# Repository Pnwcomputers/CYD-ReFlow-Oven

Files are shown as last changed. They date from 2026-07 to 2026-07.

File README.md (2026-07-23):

# 🌡️ DIY CYD Reflow Oven Controller

> **⚠️ SAFETY WARNING:** This project involves mains AC voltage, appliance modification, and high heat. Incorrect wiring can cause electric shock, fire, equipment damage, or severe injury. Do not attempt this unless you are experienced and comfortable working with mains AC wiring. Always verify wiring with a meter, confirm current ratings, use proper strain relief, bond ground correctly, and never leave the oven unattended while operating.

## 📖 Overview

This is a custom-built, cost-conscious reflow toaster oven controller designed for soldering Surface Mount Technology (SMT) printed circuit boards. It serves as a lower-cost alternative to reference designs like the [Adafruit EZ Make Oven](https://learn.adafruit.com/ez-make-oven/overview), leveraging the popular [**Cheap Yellow Display (CYD)**](https://www.elecrow.com/2-8inch-esp32-miner-lcd-display-2pcs-cryptocurrency-solo-miner-with-1000kh-s-hashrate.html) ESP32 touchscreen module.

The controller is housed in a standalone, 3D-printed bench enclosure sitting safely adjacent to the toaster oven.

### How It Works

* **Control:** Switches oven heating elements via a Solid State Relay (SSR) using slow-PWM control (2-second window).
* **Sensing:** Reads internal chamber temperatures using a K-type thermocouple paired with a MAX6675 digitizer module.
* **Safety:** A Shelly 1PM Gen4 smart relay sits in the oven's hot conductor as an independent master cutoff with real-time power metering.
* **UI/UX:** Displays live reflow profiles, temperature graphs, and touch targets directly on the CYD screen.

---

## ✨ Features & Project Status

* **Core UI:** CYD Display, capacitive touch, and status LED are fully validated.
* **Sensing:** MAX6675 reading verified with a live rendering graph on the screen.
* **AC Distribution:** ✅ **Validated.** Inlet → Shelly → KP200 branch energized and confirmed. Shelly joins Wi-Fi and reports metering; KP200 powers the CYD via USB adapter; CYD boots on mains power.
* **Control:** Slow-PWM SSR control logic scaffolded. SSR load path (`T2` → oven) not yet connected.
* **Enclosure:** OpenSCAD parametric design optimized to print flat on a Bambu X1C without supports.
* **Safety Isolation:** Internal structural barrier physically separates high-voltage AC mains from low-voltage DC control logic.
* **Triple-layer Fail-safes:** Physical fused rocker switch, a Shelly 1PM Gen4 in the oven's hot path (survives a shorted SSR), and a KP200 controlling CYD supply power.

---

## 🛠️ Bill of Materials (BOM)

| Component | Part / Model | Notes |
| :--- | :--- | :--- |
| **Microcontroller / UI** | [AITRIP CYD ESP32-2432S028R](https://a.co/d/0eqnJxus) | 2.8" resistive touchscreen unit |
| **Toaster Oven** | [Black & Decker TO1313SBD](https://a.co/d/00ZCCpC5) | 1150 W @ 120 V = **9.6 A continuous** |
| **Thermocouple Amp** | [MAX6675 Module + K-Type Thermocouple Probe](https://a.co/d/0htQOedm) | Cold-junction compensated K-type digitizer with probe |
| **Solid State Relay** | [Inkbird SSR-40DA + Aluminum Heatsink](https://a.co/d/078ydj3f) | PID element — chops AC hot line to the oven |
| **Smart Master Relay** | [Shelly 1PM Gen4](https://a.co/d/01A2Ngha) (`S4SW-001P16EU`) | 16 A resistive, power metering, in the oven's hot path |
| **AC Power Inlet** | [3Dman Fused IEC C14 + Rocker Switch](https://a.co/d/0f6DD4BR) | Single-pole rocker, switches hot only |
| **Accessory Outlet** | [KP200 Smart Outlet Module](https://a.co/d/0it13pHO) | **Always-live**, feeds CYD 5 V via USB adapter. Top socket blanked |
| **Oven Feed** | [Female trailing lead](https://a.co/d/0cmD64dU) for power | Exits the 13 mm cable gland on the left side wall |
| **Splices** | [Wago](https://a.co/d/0g3QaYkX) 221-series lever nuts | Ground junction; neutral junction when the oven lead is added |
| **Enclosure Material** | ASA *(Preferred)* / PETG *(Min)* | **Do not use PLA** (susceptible to oven-ambient warp) |

---

## 📁 Repository Structure

```text
CYD-ReFlow-Oven/
├── 3MF/                                            # Slicer-ready, pre-arranged plates
│   └── reflow-enclosure-v9_9-compact-x1.3mf        # Combined slicer assembly setup
├── OpenSCAD/                                       # Parametric physical source CAD
│   └── reflow-enclosure-flat-v10_3-compact-x1c.scad  # ✅ CURRENT master source of record
├── STL/                                            # Individual production-ready meshes
│   ├── reflow-v9_6-bottom.stl                      # Validated structural shell
│   ├── reflow-v9_6-iec-trim-plate.stl              # Dedicated trim alignment plate
│   ├── reflow-v9_9-bezel.stl                       # Top screen bezel mesh
│   └── reflow-v9_9-lid.stl                         # Pre-mirrored mating lid mesh
├── LICENSE                                         # BSD-2-Clause license file
├── README.md                                       # This file
├── diy_reflow_controller_wiring_diagram.png        # Rendered wiring schematic
└── reflow-wiring-diagram.svg                       # Vector wiring asset
```

> ⚠️ **Print Advisory:** Print the **v9.6** variant for your bottom shell/trim plate and the **v9.9** files for the lid and bezel integration. The OpenSCAD master is now **v10.3**; STL exports lag it.

---

## ⚡ System Architecture & Wiring

### Power Flow Topology

The line splits at the inlet. The oven path is switched twice; the accessory path is never switched.

```text
[Mains Wall Power]
       ↓
[3Dman Fused IEC C14 Inlet + Rocker]   ← single-pole, switches HOT only
       ↓
   FUSED HOT  ─────────────┬──────────────────────────────┐
                           ↓                              ↓
             [Shelly 1PM Gen4]  L → O           [KP200 Smart Outlet]
                           ↓                     (always live, never chopped)
                  [SSR Hot-Side Switching]                ↓
                           ↓                      bottom socket
              [13mm cable gland, left wall]              ↓
                           ↓                      [USB adapter] → CYD 5 V
        [Black & Decker Toaster Oven]              top socket blanked
```

**Why the split:** SSRs typically fail *shorted*. Killing the CYD's power cannot stop a welded triac — only a mechanical contact in the oven's own hot conductor can. The Shelly is therefore the primary cutoff. The KP200 remains a useful secondary (cutting CYD power de-energizes GPIO 1 and drops the SSR), and keeping the CYD on an always-live feed means the display and thermocouple readout stay alive during an emergency stop so you can watch the temperature fall.

> 🛑 **Design Rule:** An IEC C14 inlet is an *input* connector. Never use a male inlet as an energized power output. The power feed out to the oven uses a strain-relieved female trailing lead through the 13 mm cable gland (`ac_out_gland_dia`, left wall, y=42, z=18).

### AC Terminal Map

The Shelly's three `L` and two `N` terminals are internally paralleled, so they serve as the distribution junction — no bus bar or splice is needed on hot or neutral.

| From | To |
| :--- | :--- |
| Inlet **red** (switched, fused hot) | Shelly `L` (terminal 1) |
| Shelly `L` (terminal 2) | KP200 **load** |
| Inlet **blue** (neutral) | Shelly `N` (terminal 1) |
| Shelly `N` (terminal 2) | KP200 **neutral** |
| Inlet **yellow** (ground) | Wago 221-413 → KP200 **ground** + SSR heatsink bond |
| Shelly `O` | SSR `T1` |
| SSR `T2` | Oven trailing lead, hot |
| Shelly `SW` | *unconnected — set input to detached* |
| Shelly `L` (terminal 3) | *spare* |

The Shelly has **no ground terminal** — it is double-insulated. The SSR has **no ground terminal** either; only its metal heatsink is bonded, via a ring terminal under a heatsink screw. Never land mains ground on `T3`/`T4` (those are DC control).

### Shelly 1PM Gen4 Configuration

| Setting | Value | Reason |
| :--- | :--- | :--- |
| Power-on default | **Off** | A power blip must never energize the oven; also covers GPIO 1 boot chatter |
| Input mode | Detached / button | `SW` is unconnected |
| Overpower protection | **1400 W** | Hard backstop above the 1150 W nameplate |
| Relay duty | On before a run, off after | Never PWM — 16 A contacts are rated ~10⁵ cycles |

**Watchdog (no scripting required).** Have the CYD call this every 15 s during a run:

```
http://<shelly-ip>/rpc/Switch.Set?id=0&on=true&toggle_after=30
```

Each call re-arms a 30-second auto-off. If firmware hangs or the CYD reboots, the calls stop and the Shelly opens on its own.

**Shorted-SSR detection.** Because the 1PM meters current, a script can trip the relay when it sees meaningful draw while the controller reports idle — the one failure mode the whole safety architecture exists for.

### Wiring Architecture (Just the idea; this is NOT final)
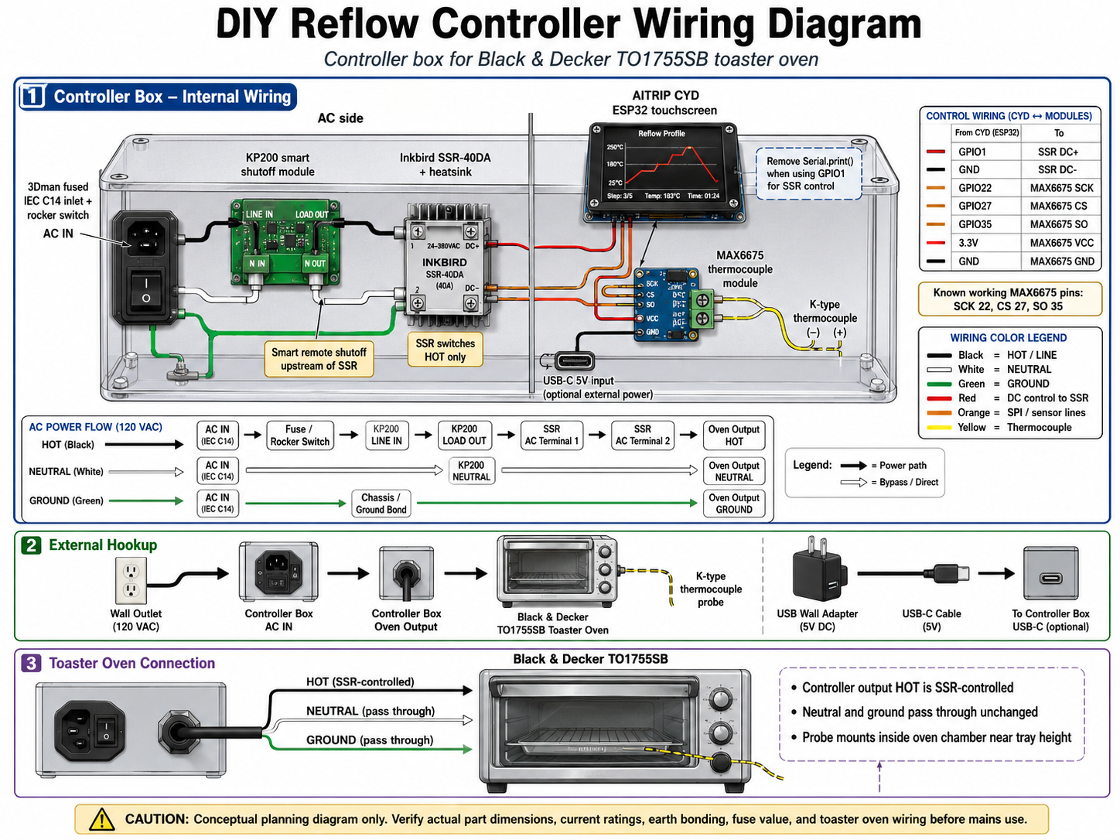
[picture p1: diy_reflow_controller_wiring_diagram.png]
DIY Reflow Controller Wiring Diagram


### Pin Configuration Mapping

The low-voltage control side links the CYD ESP32 to the MAX6675 sensor and the input side of the SSR. Due to hardware resource sharing on the CYD board, specific pins must be used:

| Function | ESP32 GPIO | Connection Target | Design Context / Gotchas |
| :--- | :--- | :--- | :--- |
| **MAX6675 SCK** | **GPIO 22** | Module Clock | Bit-banged SPI. *Do not use GPIO 21* (conflicts with CYD backlight). |
| **MAX6675 CS** | **GPIO 27** | Module Chip Select| Bit-banged SPI |
| **MAX6675 SO** | **GPIO 35** | Module Data Out | Input-only on ESP32 (perfect match for SO) |
| **SSR Control** | **GPIO 1** | SSR `T3` (DC+) | Shared with Hardware Serial TX pin. See warning below. |
| **DC Ground** | **GND** | SSR `T4` (DC−) | Common low-voltage ground reference |

> **Note:** GPIO 1 outputs 3.3 V; the SSR-40DA input is specced 3–32 VDC, so this is in spec with no headroom. If switching proves unreliable, drive the SSR from 5 V through a 2N7000 / AO3400 low-side switch.

**Divider crossings.** The AC/DC barrier has two dedicated 6 mm pass-throughs. Low-voltage lines use these and never route through the AC chamber:

* `ctrl_hole` — y=36, z=15 — SSR control pair (GPIO 1 / GND)
* `pwr_hole` — y=54, z=15 — CYD 5 V / GND

---

## 💻 Firmware & Flashing Rules

### Required Core Libraries
* `TFT_eSPI` (Configured for the respective CYD display controller)
* `XPT2046_Touchscreen`

### 🚨 Critical GPIO 1 / SSR Warning
Because **GPIO 1** is shared with the hardware serial transmit line (`TX`), any active `Serial.print()` statements or bootloader debugging data will rapidly toggle the SSR during boot or runtime.

#### Strict Upload Procedure:
1. **Isolate:** Disconnect the SSR DC+ control wire from GPIO 1 entirely.
2. **Flash:** Confirm all active `Serial.print()` calls are stripped out of production builds, then flash firmware over USB.
3. **Reconnect & Boot:** Reattach the SSR control line, then press the physical `RST` button on the CYD to initiate a clean, deterministic system boot before introducing AC power.

### Startup & Shutdown Order
Because the KP200 feed is always live, the CYD boots the instant the rocker goes on — while GPIO 1 is still chattering. Sequence accordingly:

* **Power up:** rocker on → CYD boots → *then* enable the Shelly.
* **Power down:** Shelly off → *then* rocker off.

---

## 🖨️ Enclosure & 3D Printing Production

The parametric enclosure splits the interior into isolated functional chambers with an internal physical divider wall at `divider_x = 147`.

### Enclosure Revision Milestones

* **v9.5:** CYD mounting hole pattern corrected 82×44 → **77.5×42 mm** (physically measured on the board; clone variants differ from published drawings).
* **v9.6 Platform:** Stabilized the bottom shell architecture; IEC cutout right-sized to the measured insert body (48 × 28.5 mm). Added `reflow-v9_6-iec-trim-plate.stl` retrofit spacer for shells printed with the old oversize cutout.
* **v9.9 Platform:** Refined top tolerances; display window cut now passes the full standoff depth. The lid file is intentionally pre-mirrored for printing so features map correctly when flipped into its installed state. Do not mirror it again in the slicer.
* **v10 / v10.1:** KP200 flush-mount rework from teardown measurements — window right-sized to 46 × 72 mm, yoke ear recesses, captive box-screw clearance. CYD window shift corrected 3 → **1 mm** against the physically validated printed part.
* **v10.3 (Current):** KP200 tab recesses returned to solid 1.2 mm pockets at full plate strength, with 45° sloped lead-in walls and rounded corners. Reverts the v10.2 through-slot construction.

### Slicer Configurations
* **Orientation:** All STL assets are pre-oriented for direct printing. No supports are required.
* **Infill & Perimeters:** Run a minimum of 3 perimeters paired with 30–40% Gyroid infill to handle internal heat-sink structural load.
* **Hardware:** M3 heat-set brass inserts are required for the internal mounting pillars.

---

## 🚧 Roadmap & Known Issues

### Completed Milestones ✅
* [x] Enclosure dimensions coupon-validated against physical AC components.
* [x] Confirmed SSR heatsink lid-clearance margins (8mm vertical buffer).
* [x] Split production prints to v9.6 bottom configurations and v9.9 top closures.
* [x] Successfully printed and verified structural bottom shell.
* [x] CYD screw pattern physically measured and corrected to 77.5 × 42 mm.
* [x] Smart shutoff device selected: Shelly 1PM Gen4 (16 A, metered, terminal-based — resolves the KP200's socket-only output).
* [x] AC distribution wired and energized: inlet → Shelly → KP200 → USB adapter → CYD boots on mains.
* [x] Oven peak current resolved by spec: 1150 W / 9.6 A, comfortably inside the Shelly's 16 A rating.
* [x] Confirmed the fuse is in the hot leg. Rocker on: hot pin to red reads near zero; pulling the fuse should open *red*, not blue.
* [x] Verified inlet leads gauge as 18 guage; which is marginal and may need improvement.

### Open Action Items 🛠️

**Blocking mains operation with the oven attached:**
* [ ] **Fuse value.** 9.6 A continuous means 5–6 A slow-blow will open on the first preheat ramp. Size 10 A minimum, realistically 12 A.
* [ ] **C14 inlet current headroom.** IEC 60320 C13/C14 is rated 10 A; 9.6 A continuous is 96 % of rating. Evaluate moving to a C20 inlet (16 A) with a 6.3×32 mm time-lag fuse and C19 cord.

**Build:**
* [ ] Connect SSR `T2` to the oven trailing lead and terminate at the cable gland with strain relief.
* [ ] **Verify Shelly physical placement.** The KP200 body keepout (`kp_depth_z = 44`) leaves 15 mm of floor clearance; the Shelly is 16 mm thick. Measure the real KP200 body depth — if under 40 mm the Shelly lies flat beneath it. Otherwise mount it on edge in the pocket between the inlet wire zone and the heatsink (approx. x=95–145, y=34–65), keeping distance from the heatsink given the Shelly's 40 °C ambient limit.
* [ ] Print production v9.9 lid and bezel; check fitment against bottom shell.
* [ ] Choose SSR-to-heatsink retention method (RTV high-temp silicone vs. a printed corral bracket).
* [ ] Finalize oven chassis entry point for the K-type thermocouple probe.
* [ ] Update `diy_reflow_controller_wiring_diagram.png` / `reflow-wiring-diagram.svg` to the split topology.
* [ ] Export v10.3 STLs to replace the lagging v9.6/v9.9 meshes.

**Firmware:**
* [ ] Audit codebase to completely strip out active `Serial` debugging logs.
* [ ] Implement the Shelly watchdog heartbeat (`toggle_after=30`, called every 15 s).
* [ ] Implement `KVS.Set` heating-state publishing for shorted-SSR detection.
* [ ] Design and implement target reflow curve PID logic loops in firmware.

---

## 🛑 Final Safety Checklist Before Mains Power Authorization

Do not connect the device to wall power until every item below is explicitly checked:

- [ ] **Wiring Verification:** Trace out all connections using a digital multimeter on continuity mode.
- [ ] **Mains Orientation:** Explicitly confirm that the SSR switches the **Hot / Line** conductor, *never* the Neutral conductor.
- [ ] **Fuse Leg:** Confirm the inlet's fuse is in series with the hot conductor, not the neutral.
- [ ] **Shelly Default State:** Confirm power-on default is set to **off** before energizing.
- [ ] **Ground Path Bonding:** Confirm solid earth ground continuity from the primary AC wall inlet pin to the KP200, the SSR heatsink, and the external metal oven frame.
- [ ] **Isolation Separation:** Verify low-voltage control lines route only through the divider pass-throughs and never touch the AC chamber.
- [ ] **Touch Protection:** Ensure there are zero exposed live AC terminals or raw wire conductor strands capable of being touched inside the box. `T1` and `T2` on the SSR are live whenever the Shelly relay is closed.
- [ ] **Thermal Clearance:** Ensure the SSR heatsink cooling vents are unblocked and clear.
- [ ] **Logic Verification:** Test the complete firmware logic path with the AC lines fully disconnected to ensure the CYD triggers the relay pin appropriately under mock profiles.
- [ ] **Constant Supervision:** Never leave the modified oven system unmonitored during live operations.

---

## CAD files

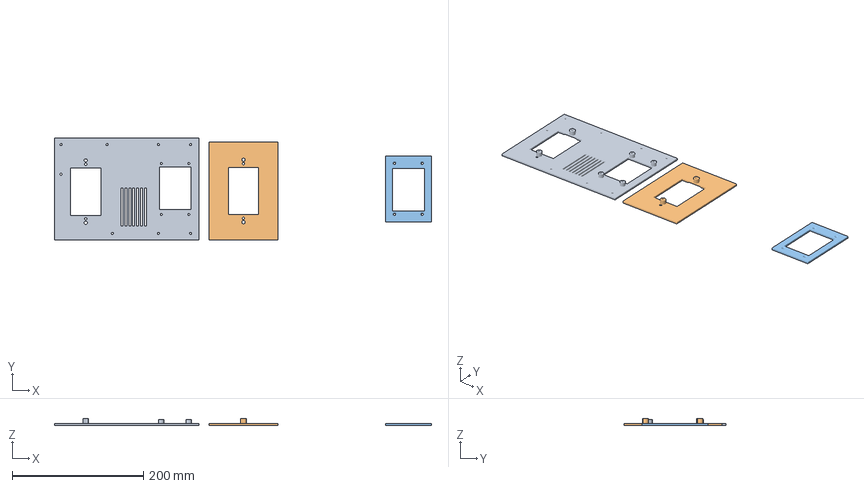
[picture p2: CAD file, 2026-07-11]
3MF/reflow-reprint-v10_3.3mf
573.5 x 155.0 x 10.0 mm
lid
kp200_coupon
cyd_bezel

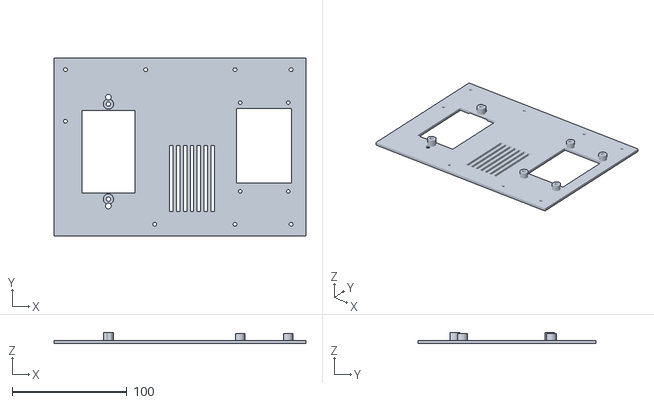
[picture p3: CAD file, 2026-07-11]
STL/reflow-v10_3-lid.stl
220.0 x 155.0 x 10.0

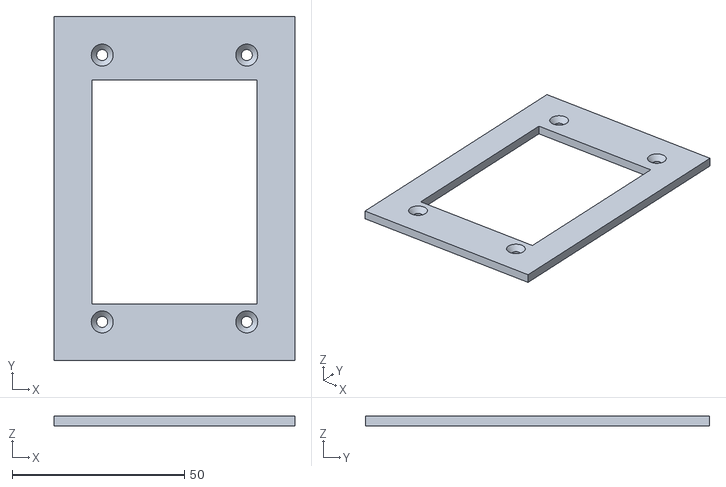
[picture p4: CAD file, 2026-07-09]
STL/reflow-v9_9-bezel.stl
70.0 x 100.0 x 3.00

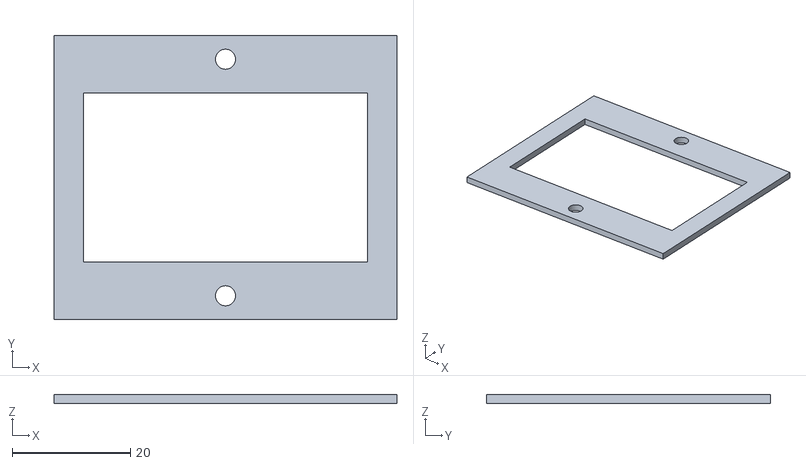
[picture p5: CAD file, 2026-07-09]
STL/reflow-v9_6-iec-trim-plate.stl
58.0 x 48.0 x 1.50

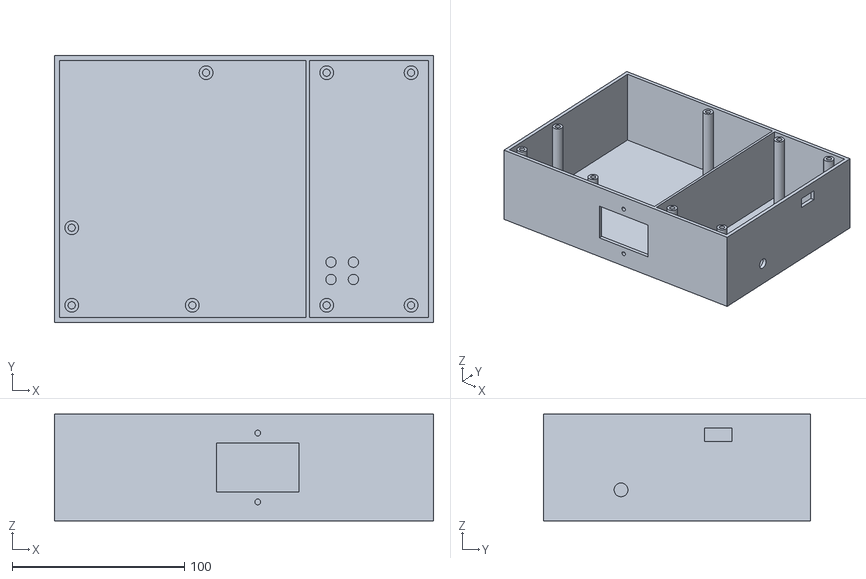
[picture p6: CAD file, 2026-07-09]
STL/reflow-v9_6-bottom.stl
220.0 x 155.0 x 62.0

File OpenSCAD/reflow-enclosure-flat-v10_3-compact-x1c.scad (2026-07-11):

// ============================================================================
//  DIY Reflow Oven Controller — Compact Flat Bench Enclosure (v10.3, X1C Fit)
//  Parametric OpenSCAD model for Bambu X1C (PETG minimum, ASA preferred)
//
//  v10.3 CHANGE: KP200 tab recesses per user spec — SOLID 1.2mm pockets kept
//  at full plate strength, now with 45-degree sloped lead-in walls, rounded
//  corners, and widened 21 -> 22mm floor. Replaces (and reverts) the v10.2
//  through-slot construction, which was rejected: it traded plate strength
//  for support-free printing without being asked.
//
//  v10.1 CHANGE: CYD window shift corrected 3 -> 1mm to match the PRINTED,
//  physically validated part (board mounted, full display visible). The 3mm
//  value was derived from clip estimates; the 1mm print is ground truth.
//
//  v10 CHANGE: KP200 flush-mount rework from teardown measurements (faceplate
//  off). Window right-sized 65x73 -> 46x72 (body is 45x71). Added 1.2mm-deep
//  recesses for the yoke ears (19x17, 1mm proud) and 5mm through-clearance for
//  the two captive box screws 6mm outboard of the mounting holes (protrude 6mm).
//  Device now seats flush; Kasa faceplate snaps over it against the lid.
//
//  v9.9 CHANGE: display window cut now passes through the full standoff depth.
//  v9.8's shifted window crossed the two ESP32-end standoff bosses by ~1mm and
//  they protruded into the opening (caught on the printed v9.8 coupon). Bosses
//  are now shaved flush with the window wall; insert wall locally ~1.15mm there.
//
//  v9.8 CHANGE: display window 66 -> 65mm, SHIFTED 3mm toward the ESP32 end.
//  Mounted-board observation: viewable area is offset 3mm toward the ESP32 end
//  relative to the hole pattern (5mm clipped there, 0mm at USB end). Symmetric
//  coverage is impossible (needs 70mm > 69mm glass). BOARD NOW INSTALLS IN ONE
//  ORIENTATION: ESP32/flex end toward the front (y=0) wall.
//
//  v9.7 CHANGE: display window long axis 60 -> 66. With the board finally
//  screwed to the TRUE hole pattern (v9.5), the 60mm window clipped the
//  MEASURED 64mm viewable region (3mm ESP32 end / 1mm USB end). 66mm symmetric
//  is the minimal window covering the viewable area in either board rotation.
//
//  v9.6 CHANGE: 3Dman IEC cutout right-sized to the MEASURED insert body
//  (47 x 27.5 x 21.5mm): cutout 52x38 -> 48x28.5. The old oversize left open
//  gaps past the tapered flange edge. Added iec_trim_plate retrofit part for
//  shells already printed with the old cutout.
//
//  v9.5 CHANGE: CYD mounting hole pattern corrected 82x44 -> 78x42 (measured
//  on printed v9.4 lid + confirmed against DIYmall dimensional drawing: holes
//  4mm from edges of the 86x50 board). Added cyd_test_coupon part.
//
//  v9.1 CHANGE: relocated two AC-side lid bosses that collided with the
//  3Dman inlet body and the SSR heatsink corner (found in pre-print audit).
//
//  v9 CHANGE: Compact X1C-friendly flat layout while keeping BOTH AC modules.
//  - 3Dman fused IEC C14 + rocker + fuse module is the DEVICE POWER INPUT.
//    It mounts on the rear wall of the AC compartment.
//  - Kasa KP200 is still used as the SMART SHUTOFF / controlled receptacle.
//    It mounts face-up through the top lid, on the AC side.
//  - CYD display mounts face-up through the top lid, on the DC side.
//  - CYD is rotated 90 degrees in the top layout to reduce total width.
//  - SSR/heatsink stays inside the AC compartment with top vents above it.
//  - All cable/connector openings are on side/rear/top faces, not the bottom,
//    so the enclosure can sit flat on the bench.
//
//  Intended AC path:
//    Wall -> external upstream safety/kill option if used -> 3Dman IEC input
//    -> KP200 line input -> KP200 controlled output -> SSR/load path -> oven.
//
//  NOTE: This is enclosure geometry only, not wiring approval. Verify current
//  ratings, fuse value, wire gauge, strain relief, grounding, creepage/clearance,
//  and the physical part dimensions before using with mains voltage.
//
//  Coordinate system:
//    X = width  (left AC side -> right DC side)
//    Y = depth  (rear wall -> front wall)
//    Z = height (floor -> lid)
// ============================================================================

/* [Render selector] */
part = "assembly"; // ["bottom","lid","bezel","assembly","all_flat","iec_test_coupon","kp200_test_coupon"]

/* [Box outer dimensions]
   220 x 155 is the compact X1C-friendly footprint. It leaves room on a
   256 x 256mm Bambu bed for skirt/brim and avoids pushing the printable edge.
   Compact trick: the CYD is rotated 90 degrees on the DC side, while the
   3Dman IEC inlet moves behind the SSR on the rear wall. */
box_w = 220;
box_d = 155;
box_h = 65;
wall_t = 3;
floor_t = 3;
lid_t = 3;

/* [AC/DC divider] */
divider_x = 147;
divider_t = 2;

/* [AC side: SSR + heatsink]
   Rotated footprint so the 80mm heatsink length runs front/back and the
   50mm side sits next to the KP200 body in X. If your heatsink is different,
   adjust heatsink_w/heatsink_d and ssr_center_x/ssr_center_y. */
heatsink_w = 50;
heatsink_d = 80;
heatsink_h = 50;
ssr_center_x = divider_x - divider_t / 2 - heatsink_w / 2 - 0.5;
ssr_center_y = 105;
heatsink_top_z = floor_t + heatsink_h;

/* [AC side: 3Dman fused IEC C14 inlet + rocker/fuse module]
   Mounted on the REAR wall. This is the device input socket, not the smart
   shutoff. Dimensions are based on common 3Dman/Amazon-style listings:
   approx face/body 58 x 48 x 34mm. Print the coupon and measure your part. */
inlet_face_w = 58;          // visible/flange face width on rear wall, X
inlet_face_h = 48;          // visible/flange face height on rear wall, Z
inlet_body_depth = 21.5;    // v9.6: MEASURED — body insert depth behind flange is 21.5mm (was 34 assumed)
inlet_wire_clearance_depth = 15;
inlet_cutout_w = 48;        // v9.6: was 52. MEASURED body is 47mm long; 0.5mm/side clearance. Old oversize left gaps past the tapered flange
inlet_cutout_h = 28.5;      // v9.6: was 38. MEASURED body is 27.5mm tall; 0.5mm/side. Old 38 left ~5mm exposed gaps above/below body
inlet_center_x = 118;
inlet_center_z = 31;
inlet_screw_pattern = "vertical"; // ["vertical","horizontal","none"]
inlet_screw_spacing = 40;
inlet_screw_dia = 3.4;

/* [AC side: KP200 smart outlet / smart shutoff]
   Top-lid mount. The KP200 face/yoke footprint is treated as 85 x 129mm.
   Here it is rotated so:
   - KP200 width runs along X
   - KP200 long mounting axis runs along Y
   - KP200 body depth runs downward from the lid along Z

   OPEN QUESTION: confirm the exact KP200 body/yoke dimensions and screw
   spacing on the physical device before final print. */
kp_wid_x = 85;
kp_len_y = 129;
kp_depth_z = 44;
kp_screw_spacing = 83;      // standard device/yoke screw spacing, along Y here
kp_center_x = wall_t + 2 + kp_wid_x / 2;
kp_center_y = box_d - wall_t - 6 - kp_len_y / 2;
kp_window_x = 46;           // v10: was 65. MEASURED recessed body is 45mm wide; 0.5mm/side. Old opening was 20mm oversize
kp_window_y = 72;           // v10: was 73 (v9.2). MEASURED body length 71mm; 0.5mm/side
// v10 flush-mount features (from KP200 teardown with faceplate removed):
kp_ear_w = 22;              // v10.3: was 21; widened per request. Recess FLOOR width, X (tab measured 19mm wide, 1mm proud)
kp_ear_h = 20;              // recess floor height, Y (tab measured 17mm tall)
kp_ear_recess = 1.2;        // recess depth into lid outer face; tab proud 1mm + tolerance
kp_ear_corner_r = 3;        // v10.3: rounded recess corners
kp_ear_chamfer = 1.2;       // v10.3: 45-degree sloped lead-in walls; opening at the surface is 2*this larger than the floor. SOLID pocket — full plate strength retained.
kp_capscrew_offset = 6;     // KP200's captive box screws sit 6mm OUTBOARD of each mounting hole...
kp_capscrew_protrude = 6;   // ...and protrude 6mm rearward: they need through-clearance to seat flush
kp_capscrew_clear_dia = 5;  // clears the ~3.5mm screw shank; kept small because it nicks the 9mm yoke boss edge (insert wall stays >1.2mm)
kp_lid_boss_h = 7;
kp_lid_boss_dia = 9;
kp_insert_dia = 4.5;
kp_insert_depth = 5;
kp_screw_clear_dia = 3.8;

/* [AC side: cable gland / output to oven]
   Put this on the LEFT side wall, rear-ish, so oven/load wiring exits sideways
   and the bottom remains completely flat. */
ac_out_gland_dia = 13;
ac_out_gland_y = 42;
ac_out_gland_z = 18;
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

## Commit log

2026-07-01 Update wiring diagram section in README
    Removed markdown formatting for wiring diagram section in README.
2026-07-09 Fix formatting of Solid State Relay description
2026-07-09 Update AC Power Inlet description in README
2026-07-21 Update Smart Master Relay link in README.md
2026-07-23 Update Wiring Architecture section to indicate it's a draft
    Clarify that the wiring architecture is a preliminary idea.
